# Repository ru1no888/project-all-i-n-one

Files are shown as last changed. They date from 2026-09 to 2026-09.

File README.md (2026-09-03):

# ระบบอุปกรณ์สวมใส่ติดตามสัญญาณชีพสุขภาพและเว็บแอปพลิเคชันบริหารจัดการคิวผู้ป่วยนอก
### (Hospital Queue Patient Portal & Smartwatch Health Monitoring)

---

## 📌 บทนำและภาพรวมโครงงาน (Overview)
โครงงานนี้เป็นการวิจัยและพัฒนานวัตกรรมระบบอุปกรณ์สวมใส่อัจฉริยะ (Smartwatch) ร่วมกับเว็บแอปพลิเคชันบริหารจัดการคิวผู้ป่วยนอกของโรงพยาบาล เพื่อยกระดับความปลอดภัยของผู้ป่วยในระหว่างรอรับการตรวจรักษา โดยระบบสามารถ:
1. **ติดตามสัญญาณชีพแบบเรียลไทม์ (Continuous Vital Signs Monitoring):** วัดอัตราการเต้นของหัวใจ (Heart Rate) และระดับความอิ่มตัวของออกซิเจนในเลือด ($SpO_2$) พร้อมคำนวณดัชนีช็อก (Shock Index: $SI = \frac{HR}{SBP}$) เพื่อประเมินภาวะวิกฤตของผู้ป่วย
2. **ตรวจจับอุบัติเหตุการหกล้ม (Multi-Stage Fall Detection):** ตรวจจับสภาวะการตกอิสระ (Free-fall), แรงกระแทก (Impact $SVM > 2.5g$) และสภาวะแน่นิ่งผิดปกติ (Inactivity) ด้วยเซนเซอร์ IMU 6 แกน
3. **จัดลำดับความเร่งด่วนของคิวอัตโนมัติ (Dynamic Queue Prioritization):** คัดกรองและปรับลำดับคิวผู้ป่วยตามหลักเกณฑ์ฉุกเฉิน ESI Version 4 ผ่านระบบ AI Triage เมื่อพบสัญญาณชีพวิกฤต
4. **แจ้งเตือนและส่งข้อมูลแบบทันที (Realtime Communication):** ส่งสัญญาณเตือนไปยังห้องพยาบาลและบุคลากรทางการแพทย์ผ่าน WebSockets ทันทีที่มีเหตุฉุกเฉิน

---

## 📁 โครงสร้างโฟลเดอร์ภายในโปรเจกต์ (Repository Structure)

```text
├── 01_เล่มรายงานโครงงาน_Thesis/
│   ├── เล่มรายงานโครงงาน_ฉบับสมบูรณ์_FINAL_v3_IEEE.docx    # เล่มรายงานโครงงานฉบับสมบูรณ์ (ฟอร์แมต IEEE มทร.อีสาน ขอนแก่น)
│   ├── เล่มรายงานโครงงาน_ฉบับสมบูรณ์_FINAL_v3_IEEE.pdf     # ไฟล์ PDF เล่มสมบูรณ์ (103 หน้า พร้อมตรวจ/พิมพ์)
│   ├── ECP-P01_แบบร่างโครงงานวิศวกรรมคอมพิวเตอร์_ฉบับปรับปรุงสมบูรณ์_v14.docx # แบบร่างข้อเสนอโครงงาน (Proposal v14)
│   ├── ECP-P01_แบบร่างโครงงานวิศวกรรมคอมพิวเตอร์_ฉบับปรับปรุงสมบูรณ์_v14.pdf  # ไฟล์ PDF แบบร่างโครงงาน (20 หน้าเต็ม)
│   └── ร่างเดิมและไฟล์สำรอง_Archive/                     # โฟลเดอร์สำรองไฟล์ดราฟต์เดิมทั้งหมดอย่างปลอดภัย
│
├── 02_ฮาร์ดแวร์และวงจร_Hardware/
│   ├── smartwatch_component_pinouts.html                 # ผังการต่อสาย Pinout และวงจรเซนเซอร์แบบ Interactive Web
│   ├── component_pinouts/                                # แผนภาพ Pinout รายชิ้นส่วน
│   ├── pcb_design/                                       # ไฟล์ออกแบบแผ่นวงจรพิมพ์ PCB (KiCad / EasyEDA)
│   └── pcb_design.zip                                    # ไฟล์บีบอัดสำหรับส่งโรงงานผลิต PCB (Gerber Files)
│
├── 03_ซอร์สโค้ดและเว็บแอป_SourceCode/
│   ├── repo_README.md                                    # เอกสารคู่มือการติดตั้งและการรัน Frontend Web App
│   ├── repo_ARCHITECTURE.md                              # สถาปัตยกรรมระบบ Frontend & Backend API Spec
│   ├── repo_package.json                                 # รายการ Dependencies (Next.js 14, React, Tailwind CSS)
│   ├── repo_patient-api.ts                               # API Client Module สำหรับเชื่อมต่อระบบโรงพยาบาล
│   ├── repo_types.ts                                     # TypeScript Interface สำหรับ Patient, Queue, Vital Signs
│   └── repo_mock_backend.py                              # สคริปต์จำลองเซิร์ฟเวอร์ Mock API สำหรับการทดสอบระบบ
│
├── 04_ไฟล์ข้อมูลและเครื่องมือเสริม_Assets_Tools/
│   ├── extracted_assets/                                 # รูปภาพและกราฟิกประกอบที่ใช้ในเอกสาร
│   ├── extracted_ch4_images/                             # ภาพผลการทดลองและการทดสอบระบบในบทที่ 4
│   ├── logo/                                             # ตราสัญลักษณ์มหาวิทยาลัยเทคโนโลยีราชมงคลอีสาน
│   └── build_full_thesis.py                              # สคริปต์สำหรับบิวด์และจัดรูปแบบรูปเล่มอัตโนมัติ
│
├── AGENTS.md                                             # ข้อกำหนดและแนวทางสำหรับ AI Assistant
├── GEMINI.md                                             # กฎระเบียบข้อบังคับและ Memory Protocol ประจำโปรเจกต์
├── PROJECT_MEMORY.md                                     # บันทึกความจำระยะยาว ประวัติการพัฒนา และข้อสรุปงาน
└── README.md                                             # เอกสารภาพรวมโปรเจกต์ (ไฟล์นี้)
```

---

## 🛠️ รายละเอียดสเปกฮาร์ดแวร์และเซนเซอร์ (Hardware Specifications)

| ส่วนประกอบ (Component) | รายละเอียด (Specification) | ฟังก์ชันการทำงาน |
|---|---|---|
| **MCU Controller** | Seeed Studio XIAO ESP32-C3 | หน่วยประมวลผลหลัก รองรับ Wi-Fi 2.4GHz และ BLE 5.0 |
| **Biometric Sensor** | MAX32664 Biometric Hub + MAX30102 PPG | ตรวจวัด Pulse Rate และ $SpO_2$ ด้วยความแม่นยำสูง |
| **Motion Sensor** | MPU-6050 (6-Axis Accel + Gyro) | ตรวจจับการเคลื่อนไหวและการหกล้ม 3 ขั้นตอน (SVM Analysis) |
| **Power Management** | TP4056 + แบตเตอรี่ LiPo 3.7V (500mAh) | วงจรชาร์จแบตเตอรี่ พร้อมวงจรแบ่งแรงดันวัดระดับแบตเตอรี่ |
| **Display** | จอแสดงผล OLED 0.96 นิ้ว (I2C) | แสดงผลอัตราเต้นหัวใจ, ออกซิเจนในเลือด และสถานะคิว |

---

## 💻 เทคโนโลยีฝั่งเว็บแอปพลิเคชัน (Software Stack)
- **Frontend Framework:** Next.js (App Router), React 18, TypeScript
- **Styling & UI:** Tailwind CSS, Lucide Icons, Headless UI
- **Database & Realtime:** Google Cloud Firestore, WebSockets
- **Deployment:** Vercel / Docker Container

---

## 👥 ผู้จัดทำโครงงาน (Contributors)
- **นายปรเมศว์ เดนนิส โฮค อาร์ริงตัน** (Mr. Porramet Dennis Hoke Arrington)
- **นายธนกร สุภาวรรณชัย** (Mr. Thanakorn Suphawanchai)

**สาขาวิชาวิศวกรรมคอมพิวเตอร์ คณะวิศวกรรมศาสตร์**  
**มหาวิทยาลัยเทคโนโลยีราชมงคลอีสาน วิทยาเขตขอนแก่น**  
**อาจารย์ที่ปรึกษาโครงงาน:** อาจารย์อรินธร เจษฎาเมธาขจร  
**ปีการศึกษา:** 2568 (Academic Year 2025)

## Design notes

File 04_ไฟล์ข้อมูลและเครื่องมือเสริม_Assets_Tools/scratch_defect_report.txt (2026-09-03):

=== 1. PLACEHOLDER & ERROR SCAN ===

=== 2. FIGURE NUMBERING SCAN ===
P138: รูปที่ 3.1 -> รูปที่ 3.1 แผนภาพ Use Case Diagram และสถาปัตยกรรมระบบรวม . . . . . . . . 48
P139: รูปที่ 3.2 -> รูปที่ 3.2 โมเดล 3D CAD ตัวเรือนนาฬิกา Smartwatch (SmartWatchV13 Comparison) . 5
P140: รูปที่ 3.3 -> รูปที่ 3.3 ผังการทำงานของเฟิร์มแวร์ฮาร์ดแวร์บน ESP32-C3 (Hardware Flowchart) . 5
P141: รูปที่ 3.4 -> รูปที่ 3.4 ผังการทำงานของระบบคลาวด์และเว็บแดชบอร์ด (Software Flowchart) . 73
P142: รูปที่ 4.1 -> รูปที่ 4.1 หน้าจอเข้าสู่ระบบผ่าน ThaID และ PIN . . . . . . . . . . . . . 79
P143: รูปที่ 4.2 -> รูปที่ 4.2 หน้าจอเข้าสู่ระบบด้วยรหัส PIN ส่วนบุคคล . . . . . . . . . . . 80
P144: รูปที่ 4.3 -> รูปที่ 4.3 หน้าจอลงทะเบียนผู้ป่วยใหม่ ส่วนข้อมูลส่วนบุคคล . . . . . . . . 81
P145: รูปที่ 4.4 -> รูปที่ 4.4 หน้าจอระบุอาการสำคัญ โรคประจำตัว และประวัติแพ้ยา . . . . . . . 82
P146: รูปที่ 4.5 -> รูปที่ 4.5 หน้าจอบันทึกยาประจำ ที่อยู่ ผู้ติดต่อฉุกเฉิน และการยินยอม PDPA . 83
P147: รูปที่ 4.6 -> รูปที่ 4.6 หน้าจอบัตรคิวรับบริการดิจิทัลบนสมาร์ตโฟนของผู้ป่วย . . . . . . 84
P148: รูปที่ 4.7 -> รูปที่ 4.7 หน้าจอแสดงผลคิวรอตรวจรวมทั้งแผนก (Live OPD Board) . . . . . . 85
P149: รูปที่ 4.8 -> รูปที่ 4.8 หน้าจอตรวจสอบคิวสดพร้อมป๊อปอัปบัตรคิวดิจิทัล . . . . . . . . . 86
P150: รูปที่ 4.9 -> รูปที่ 4.9 หน้าจอข้อมูลส่วนบุคคลและข้อมูลสุขภาพผู้ป่วย . . . . . . . . . 87
P151: รูปที่ 4.10 -> รูปที่ 4.10 หน้าจอรายการนัดหมายตรวจรักษา . . . . . . . . . . . . . . . . 87
P152: รูปที่ 4.11 -> รูปที่ 4.11 หน้าจอประวัติการรับบริการและการบันทึกค่าสัญญาณชีพ . . . . . . 88
P153: รูปที่ 4.12 -> รูปที่ 4.12 หน้าจอรายละเอียดข้อมูลผู้ป่วยและสรุปประวัติสุขภาพ . . . . . . 88
P154: รูปที่ 4.13 -> รูปที่ 4.13 หน้าต่างยืนยันการยกเลิกคิวรับบริการ (ขั้นตอนที่ 1) . . . . . 89
P155: รูปที่ 4.14 -> รูปที่ 4.14 หน้าต่างยืนยันการยกเลิกคิวรับบริการ (ขั้นตอนที่ 2) . . . . . 89
P156: รูปที่ 4.15 -> รูปที่ 4.15 หน้าจอแสดงสถานะเมื่อไม่มีคิวรับบริการในขณะนั้น . . . . . . . 90
P157: รูปที่ 4.16 -> รูปที่ 4.16 หน้าต่างแจ้งเตือนเมื่อผู้ป่วยมีคิวที่กำลังรอตรวจอยู่แล้ว . . 90
P158: รูปที่ 4.17 -> รูปที่ 4.17 หน้าต่างยืนยันการออกจากระบบ . . . . . . . . . . . . . . . . . 91
P159: รูปที่ 4.18 -> รูปที่ 4.18 หน้าจอการตั้งค่าระบบและความปลอดภัย . . . . . . . . . . . . . 91
P160: รูปที่ 4.19 -> รูปที่ 4.19 หน้าจอกรอกรหัส PIN 6 หลักสำหรับความปลอดภัย . . . . . . . . . 91
P161: รูปที่ 4.20 -> รูปที่ 4.20 หน้าจอยืนยันรหัส PIN 6 หลัก . . . . . . . . . . . . . . . . . 92
P162: รูปที่ 4.21 -> รูปที่ 4.21 หน้าจอแจ้งเตือนตั้งรหัส PIN สำเร็จ . . . . . . . . . . . . . 92
P163: รูปที่ 4.22 -> รูปที่ 4.22 หน้าจอปลดล็อกแอปพลิเคชันด้วย PIN . . . . . . . . . . . . . . 92
P164: รูปที่ 4.23 -> รูปที่ 4.23 หน้าจอแจ้งเตือนเมื่อกรอกรหัส PIN ไม่ถูกต้อง . . . . . . . . . 93
P165: รูปที่ 4.24 -> รูปที่ 4.24 หน้าจอตั้งค่าขนาดตัวอักษร (Accessibility) สำหรับผู้สูงอายุ . 93
P166: รูปที่ 4.25 -> รูปที่ 4.25 หน้าจอนโยบายความเป็นส่วนตัวและคุ้มครองข้อมูลสุขภาพ (PDPA Policy) . 9
P167: รูปที่ 4.26 -> รูปที่ 4.26 หน้าจอ Landing Page ยินดีต้อนรับผู้รับบริการ . . . . . . . . 94
P331: รูปที่ 3.1 -> รูปที่ 3.1 แผนภาพ Use Case Diagram และสถาปัตยกรรมระบบรวม
P339: รูปที่ 3.2 -> รูปที่ 3.2 โมเดล 3D CAD ตัวเรือนนาฬิกา Smartwatch (SmartWatchV13 Comparison)
P341: รูปที่ 3.3 -> การทำงานของเฟิร์มแวร์บนตัวอุปกรณ์สวมใส่ถูกควบคุมด้วยเครื่องสถานะจำกัด (Finite St
P343: รูปที่ 3.3 -> รูปที่ 3.3 ผังการทำงานของเฟิร์มแวร์ฮาร์ดแวร์บน ESP32-C3 (Hardware Flowchart)
P376: รูปที่ 3.4 -> รูปที่ 3.4 ผังการทำงานของระบบคลาวด์และเว็บแดชบอร์ด (Software Flowchart)
P391: รูปที่ 4.1 -> ระบบเว็บแอปพลิเคชันได้รับการพัฒนาขึ้นอย่างสมบูรณ์ รองรับการทำงานทั้งบนอุปกรณ์คอม
P393: รูปที่ 4.1 -> รูปที่ 4.1 หน้าจอเข้าสู่ระบบผ่าน ThaID และ PIN
P395: รูปที่ 4.2 -> รูปที่ 4.2 หน้าจอเข้าสู่ระบบด้วยรหัส PIN ส่วนบุคคล
P397: รูปที่ 4.3 -> รูปที่ 4.3 หน้าจอลงทะเบียนผู้ป่วยใหม่ ส่วนข้อมูลส่วนบุคคล
P399: รูปที่ 4.4 -> รูปที่ 4.4 หน้าจอระบุอาการสำคัญ โรคประจำตัว และประวัติแพ้ยา
P401: รูปที่ 4.5 -> รูปที่ 4.5 หน้าจอบันทึกยาประจำ ที่อยู่ ผู้ติดต่อฉุกเฉิน และการยินยอม PDPA
P403: รูปที่ 4.6 -> รูปที่ 4.6 หน้าจอบัตรคิวรับบริการดิจิทัลบนสมาร์ตโฟนของผู้ป่วย
P405: รูปที่ 4.7 -> รูปที่ 4.7 หน้าจอแสดงผลคิวรอตรวจรวมทั้งแผนก (Live OPD Board)
P407: รูปที่ 4.8 -> รูปที่ 4.8 หน้าจอตรวจสอบคิวสดพร้อมป๊อปอัปบัตรคิวดิจิทัล
P409: รูปที่ 4.9 -> รูปที่ 4.9 หน้าจอข้อมูลส่วนบุคคลและข้อมูลสุขภาพผู้ป่วย
P411: รูปที่ 4.10 -> รูปที่ 4.10 หน้าจอรายการนัดหมายตรวจรักษา
P413: รูปที่ 4.11 -> รูปที่ 4.11 หน้าจอประวัติการรับบริการและการบันทึกค่าสัญญาณชีพ
P415: รูปที่ 4.12 -> รูปที่ 4.12 หน้าจอรายละเอียดข้อมูลผู้ป่วยและสรุปประวัติสุขภาพ
P417: รูปที่ 4.13 -> รูปที่ 4.13 หน้าต่างยืนยันการยกเลิกคิวรับบริการ (ขั้นตอนที่ 1)
P419: รูปที่ 4.14 -> รูปที่ 4.14 หน้าต่างยืนยันการยกเลิกคิวรับบริการ (ขั้นตอนที่ 2)
P421: รูปที่ 4.15 -> รูปที่ 4.15 หน้าจอแสดงสถานะเมื่อไม่มีคิวรับบริการในขณะนั้น
P423: รูปที่ 4.16 -> รูปที่ 4.16 หน้าต่างแจ้งเตือนเมื่อผู้ป่วยมีคิวที่กำลังรอตรวจอยู่แล้ว
P425: รูปที่ 4.17 -> รูปที่ 4.17 หน้าต่างยืนยันการออกจากระบบ
P427: รูปที่ 4.18 -> รูปที่ 4.18 หน้าจอการตั้งค่าระบบและความปลอดภัย
P429: รูปที่ 4.19 -> รูปที่ 4.19 หน้าจอกรอกรหัส PIN 6 หลักสำหรับความปลอดภัย
P431: รูปที่ 4.20 -> รูปที่ 4.20 หน้าจอยืนยันรหัส PIN 6 หลัก
P433: รูปที่ 4.21 -> รูปที่ 4.21 หน้าจอแจ้งเตือนตั้งรหัส PIN สำเร็จ
P435: รูปที่ 4.22 -> รูปที่ 4.22 หน้าจอปลดล็อกแอปพลิเคชันด้วย PIN
P437: รูปที่ 4.23 -> รูปที่ 4.23 หน้าจอแจ้งเตือนเมื่อกรอกรหัส PIN ไม่ถูกต้อง
P439: รูปที่ 4.24 -> รูปที่ 4.24 หน้าจอตั้งค่าขนาดตัวอักษร (Accessibility) สำหรับผู้สูงอายุ
P441: รูปที่ 4.25 -> รูปที่ 4.25 หน้าจอนโยบายความเป็นส่วนตัวและคุ้มครองข้อมูลสุขภาพ (PDPA Policy)
P443: รูปที่ 4.26 -> รูปที่ 4.26 หน้าจอ Landing Page ยินดีต้อนรับผู้รับบริการ

=== 3. TABLE NUMBERING SCAN ===
P119: ตารางที่ 1.1 -> ตารางที่ 1.1 แผนการดำเนินงานและแผนภูมิแกนต์ตลอด 2 ภาคการศึกษา . . . . . . 8
P120: ตารางที่ 1.2 -> ตารางที่ 1.2 ประมาณการงบประมาณและค่าใช้จ่ายในการพัฒนาโครงงาน (BOM) . . . . 9
P121: ตารางที่ 2.1 -> ตารางที่ 2.1 เกณฑ์ค่ามาตรฐานสัญญาณชีพและระดับภาวะวิกฤตทางการแพทย์ (NEWS/MEWS) . 
P122: ตารางที่ 2.2 -> ตารางที่ 2.2 การเปรียบเทียบคุณสมบัติของเซนเซอร์ PPG และชิปประมวลผล . . . 22
P123: ตารางที่ 2.3 -> ตารางที่ 2.3 สรุปและเปรียบเทียบผลการศึกษางานวิจัยที่เกี่ยวข้องกับโครงงาน . 43
P124: ตารางที่ 3.1 -> ตารางที่ 3.1 การเชื่อมต่อพินระหว่าง ESP32-C3 กับโมดูลเซนเซอร์และอุปกรณ์ต่อพ่วง .
P125: ตารางที่ 3.2 -> ตารางที่ 3.2 แบบจำลองการแปลงค่าแรงดันเป็นร้อยละความจุแบตเตอรี่ LiPo (LUT) . 58
P126: ตารางที่ 3.3 -> ตารางที่ 3.3 ตารางโครงสร้างฐานข้อมูล 8 เอนทิตีหลักของระบบ . . . . . . . . 61
P127: ตารางที่ 3.4 -> ตารางที่ 3.4 ข้อกำหนดการสื่อสารข้อมูลระหว่างระบบเว็บและแม่ข่าย (API Contract Tab
P128: ตารางที่ 4.1 -> ตารางที่ 4.1 ผลการทดสอบอัตราการใช้พลังงานและระยะเวลาทำงานต่อเนื่องของอุปกรณ์ . 9
P129: ตารางที่ 4.2 -> ตารางที่ 4.2 ผลการเปรียบเทียบความแม่นยำของเซนเซอร์ Smartwatch กับเครื่องมือมาตรฐ
P130: ตารางที่ 4.3 -> ตารางที่ 4.3 ตาราง Confusion Matrix และประสิทธิภาพการจำแนกความรุนแรงของ AI Triag
P131: ตารางที่ 4.4 -> ตารางที่ 4.4 ผลการทดสอบประสิทธิภาพการตรวจจับการหกล้มและการจำแนกกิจกรรมประจำวัน .
P132: ตารางที่ 4.5 -> ตารางที่ 4.5 ผลการทดสอบกรณีจำลองการยืนยันและปรับแก้ผลการคัดแยกโดยพยาบาล . 105
P133: ตารางที่ 4.6 -> ตารางที่ 4.6 ตารางสรุปผลการประเมินการบรรลุวัตถุประสงค์ของโครงงาน (Objective Matr
P134: ตารางที่ 4.7 -> ตารางที่ 4.7 ผลการประเมินระดับความพึงพอใจของผู้ใช้งานต่อระบบ (N = 30) . 109
P249: ตารางที่ 1.1 -> การดำเนินงานโครงงานมีระยะเวลาตลอด 2 ภาคการศึกษา (ปีการศึกษา 2568) โดยมีแผนภูมิแก
P250: ตารางที่ 1.1 -> ตารางที่ 1.1 แผนการดำเนินงานและแผนภูมิแกนต์ตลอด 2 ภาคการศึกษา
P253: ตารางที่ 1.2 -> ค่าใช้จ่ายในการจัดหาอุปกรณ์ฮาร์ดแวร์ ชิ้นส่วนอิเล็กทรอนิกส์ และเครื่องมือในการพั
P254: ตารางที่ 1.2 -> ตารางที่ 1.2 ประมาณการงบประมาณและค่าใช้จ่ายในการพัฒนาโครงงาน (BOM)
P281: ตารางที่ 2.1 -> ตารางที่ 2.1 เกณฑ์ค่ามาตรฐานสัญญาณชีพและระดับภาวะวิกฤตทางการแพทย์ (NEWS/MEWS)
P292: ตารางที่ 2.2 -> ตารางที่ 2.2 การเปรียบเทียบคุณสมบัติของเซนเซอร์ PPG และชิปประมวลผล
P315: ตารางที่ 2.3 -> คณะผู้จัดทำได้ศึกษาและทบทวนวรรณกรรมที่เกี่ยวข้องกับการพัฒนาอุปกรณ์สวมใส่ติดตามสั
P316: ตารางที่ 2.3 -> ตารางที่ 2.3 สรุปและเปรียบเทียบผลการศึกษางานวิจัยที่เกี่ยวข้องกับโครงงาน
P333: ตารางที่ 3.1 -> การเชื่อมต่อระหว่างบอร์ด Seeed Studio XIAO ESP32-C3 กับโมดูลเซนเซอร์และอุปกรณ์ต่
P334: ตารางที่ 3.1 -> ตารางที่ 3.1 การเชื่อมต่อพินระหว่าง ESP32-C3 กับโมดูลเซนเซอร์และอุปกรณ์ต่อพ่วง
P348: ตารางที่ 3.2 -> 4) Battery Look-Up Table (LUT): แปลงค่าแรงดันแบตเตอรี่เป็นร้อยละความจุตามเส้นโค้
P349: ตารางที่ 3.2 -> ตารางที่ 3.2 แบบจำลองการแปลงค่าแรงดันเป็นร้อยละความจุแบตเตอรี่ LiPo (LUT)
P352: ตารางที่ 3.3 -> ฐานข้อมูลของระบบได้รับการออกแบบตามโครงสร้างเชิงสัมพันธ์ ประกอบด้วย 8 เอนทิตีหลัก
P353: ตารางที่ 3.3 -> ตารางที่ 3.3 ตารางโครงสร้างฐานข้อมูล 8 เอนทิตีหลักของระบบ
P363: ตารางที่ 3.4 -> การรับส่งข้อมูลระหว่างอุปกรณ์สวมใส่ เว็บแอปพลิเคชัน และระบบแม่ข่ายดำเนินการผ่าน 
P364: ตารางที่ 3.4 -> ตารางที่ 3.4 ข้อกำหนดการสื่อสารข้อมูลระหว่างระบบเว็บและแม่ข่าย (API Contract Tab
P445: ตารางที่ 4.1 -> อุปกรณ์ Smartwatch ต้นแบบได้รับการประกอบและทดสอบการทำงานของวงจรอิเล็กทรอนิกส์อย่
P446: ตารางที่ 4.1 -> ตารางที่ 4.1 ผลการทดสอบอัตราการใช้พลังงานและระยะเวลาทำงานต่อเนื่องของอุปกรณ์
P449: ตารางที่ 4.2 -> การทดสอบความถูกต้องและแม่นยำของเซนเซอร์ PPG (MAX32664 / MAX30102) บนอุปกรณ์ Smar
P450: ตารางที่ 4.2 -> ตารางที่ 4.2 ผลการเปรียบเทียบความแม่นยำของเซนเซอร์ Smartwatch กับเครื่องมือมาตรฐ
P453: ตารางที่ 4.3 -> ผลการทดสอบแบบจำลอง AI Triage ในการจำแนกระดับความรุนแรง 5 ระดับ (RED, PINK, YELLO
P454: ตารางที่ 4.3 -> ตารางที่ 4.3 ตาราง Confusion Matrix และประสิทธิภาพการจำแนกความรุนแรงของ AI Triag
P456: ตารางที่ 4.3 -> จากตารางที่ 4.3 พบว่าระบบมีความแม่นยำรวม (Overall Accuracy) เท่ากับร้อยละ 91.20 
P458: ตารางที่ 4.4 -> การทดสอบอัลกอริทึม Multi-Stage Fall Detection แบบ Finite State Machine ประกอบด้ว
P459: ตารางที่ 4.4 -> ตารางที่ 4.4 ผลการทดสอบประสิทธิภาพการตรวจจับการหกล้มและการจำแนกกิจกรรมประจำวัน
P466: ตารางที่ 4.5 -> การทดสอบการทำงานของ Nurse Dashboard ร่วมกับแนวคิด Human-in-the-loop แสดงตัวอย่าง
P467: ตารางที่ 4.5 -> ตารางที่ 4.5 ผลการทดสอบกรณีจำลองการยืนยันและปรับแก้ผลการคัดแยกโดยพยาบาล
P470: ตารางที่ 4.6 -> การประเมินผลการดำเนินงานเทียบกับวัตถุประสงค์ทั้ง 6 ข้อของโครงงาน แสดงสรุปในตาราง
P471: ตารางที่ 4.6 -> ตารางที่ 4.6 ตารางสรุปผลการประเมินการบรรลุวัตถุประสงค์ของโครงงาน (Objective Matr
P474: ตารางที่ 4.7 -> ผลการประเมินความพึงพอใจจากกลุ่มตัวอย่างผู้รับบริการและบุคลากรทางการแพทย์จำนวน 30
P475: ตารางที่ 4.7 -> ตารางที่ 4.7 ผลการประเมินระดับความพึงพอใจของผู้ใช้งานต่อระบบ (N = 30)

=== 4. EQUATION NUMBERING SCAN ===
P284: สมการ (2.1) -> สัญญาณชีพเป็นตัวบ่งชี้สรีรวิทยาพื้นฐานที่สะท้อนถึงการทำงานของระบบสำคัญในร่างกาย 
P288: สมการ (2.2) -> เทคนิคโฟโตพลีทิสโมกราฟี (Photoplethysmography: PPG) เป็นการตรวจวัดทางทัศนศาสตร์โ
P290: สมการ (2.3) -> จากนั้นจะนำค่า R ไปแปลงเป็นค่าความอิ่มตัวของออกซิเจนในเลือด (SpO2) ผ่านสมการเทีย
P295: สมการ (2.4) -> การตรวจจับการหกล้มด้วยเซนเซอร์วัดความเฉื่อย 6 แกน (MPU-6050) อาศัยการคำนวณค่าเวก
P336: สมการ (3.1) -> การตรวจวัดแรงดันแบตเตอรี่ใช้วงจรแบ่งแรงดัน (Voltage Divider) ความต้านทาน R1 = 10
P379: สมการ (3.2) -> 1. การทดสอบความแม่นยำเซนเซอร์สัญญาณชีพ: เปรียบเทียบค่า HR, SpO2, Skin Temp, และ 
P382: สมการ (3.4) -> 2. การทดสอบการตรวจจับการหกล้ม: จำลองการหกล้มจริง 4 รูปแบบ (ล้มไปข้างหน้า ข้างหลั

=== 5. CHAPTER HEADINGS SCAN ===
P60: บทที่ 1 บทนำ . . . . . . . . . . . . . . . . . . . . . . . . . . . . . . . 1
P71: บทที่ 2 ทฤษฎีและงานวิจัยที่เกี่ยวข้อง . . . . . . . . . . . . . . . . . . 13
P84: บทที่ 3 วิธีดำเนินงาน . . . . . . . . . . . . . . . . . . . . . . . . . . 45
P95: บทที่ 4 ผลการดำเนินงานและการทดสอบระบบ . . . . . . . . . . . . . . . . . . 78
P105: บทที่ 5 สรุปผล อภิปรายผล และข้อเสนอแนะ . . . . . . . . . . . . . . . . . 110
P110: บรรณานุกรม . . . . . . . . . . . . . . . . . . . . . . . . . . . . . . . 118
P111: ภาคผนวก . . . . . . . . . . . . . . . . . . . . . . . . . . . . . . . . 123
P112: ภาคผนวก ก: ผังวงจรและการต่อสายสัญญาณ (Schematic & BOM) . . . . . . . 124
P113: ภาคผนวก ข: ซอร์สโค้ดสำคัญของระบบ (Source Code Snippets & Contracts) . 128
P114: ภาคผนวก ค: คู่มือการใช้งานระบบ Smartwatch และ Web Dashboard . . . . . 134
P115: ภาคผนวก ง: แบบประเมินความพึงพอใจและตารางบันทึกผลการทดสอบดิบ . . . . . 140
P195: บทที่ 1
บทนำ
P272: บทที่ 2
ทฤษฎีและงานวิจัยที่เกี่ยวข้อง
P319: บทที่ 3
วิธีดำเนินงาน
P388: บทที่ 4
ผลการดำเนินงานและการทดสอบระบบ
P478: บทที่ 5
สรุปผล อภิปรายผล และข้อเสนอแนะ
P503: บรรณานุกรม
P525: ภาคผนวก ก
ผังวงจรและการต่อสายสัญญาณ (Schematic & BOM)
P532: ภาคผนวก ข
ซอร์สโค้ดสำคัญของระบบ (Source Code Snippets & Contracts)
P543: ภาคผนวก ค
คู่มือการใช้งานระบบ Smartwatch และ Web Dashboard
P560: ภาคผนวก ง
แบบประเมินความพึงพอใจและตารางบันทึกผลการทดสอบดิบ

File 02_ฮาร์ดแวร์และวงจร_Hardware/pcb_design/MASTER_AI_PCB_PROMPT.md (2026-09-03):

# 🤖 MASTER AI PCB PROMPT: SMARTWATCH CARRIER BOARD v1.0
> **คำแนะนำ:** คุณสามารถคัดลอกข้อความด้านล่างนี้ทั้งหมด นำไปวางในช่องแชทของ AI (ChatGPT, Claude, Gemini, Antigravity) เพื่อให้ AI สร้างหรือปรับปรุงไฟล์ KiCad, Gerber, PDF และโค้ดวงจรนี้ใหม่ได้ทันที 100% โดยไม่มีข้อผิดพลาด

```markdown
คุณคือวิศวกรผู้เชี่ยวชาญด้านการออกแบบวงจรพิมพ์ (Hardware & PCB Design Engineer) ระดับสูง
โปรดช่วยฉันออกแบบและสร้างไฟล์ PCB สำหรับโปรเจกต์ "SmartWatch Carrier Board v1.0" บน KiCad โดยยึดตามข้อกำหนดทางวิศวกรรมและพิกัดเรขาคณิตขั้นสูงดังต่อไปนี้อย่างเคร่งครัด:

---

### 1. ข้อมูลภาพรวมและข้อกำหนดเชิงกล (Mechanical Constraints)
1. รูปร่างบอร์ด: แผ่น PCB ทรงกลม ขนาดเส้นผ่านศูนย์กลาง Ø 44.0 mm (รัศมี R = 22.0 mm) จุดกึ่งกลางบอร์ดอยู่ที่พิกัด (X = 100.0 mm, Y = 100.0 mm) บนเลเยอร์ Edge.Cuts
2. เลเยอร์บอร์ด: PCB 2 เลเยอร์ (Top Layer: F.Cu และ Bottom Layer: B.Cu), เนื้อแผ่น FR-4 หนา 1.0 mm (เพื่อความบางสำหรับใส่นาฬิกา), ทองแดงหนา 1 oz (35 µm)
3. กฎความปลอดภัยของขอบบอร์ด (Strict Keep-In DRC Rule):
   - ขาอุปกรณ์ (Pads), รูเจาะ (Drills), ลายเส้นทองแดง (Tracks) และรูเวีย (Vias) ทั้งหมดจะต้องอยู่ภายในรัศมีปลอดภัย:
     $$\sqrt{(X - 100.0)^2 + (Y - 100.0)^2} \le 19.2\text{ mm}$$
   - รับประกันว่าทุกชิ้นส่วนจะอยู่ห่างจากขอบวงกลมจริงอย่างน้อย 2.8 mm ห้ามมีส่วนใดยื่นหลุดขอบเด็ดขาด (Zero Edge Protrusion)
4. พื้นที่เว้นว่างเสาอากาศ (Antenna Keep-Out Zone):
   - สี่เหลี่ยมผืนผ้าด้านบนกึ่งกลาง (X = 93.5 ถึง 106.5 mm, Y = 81.5 ถึง 85.5 mm)
   - ห้ามวางชิ้นส่วน ห้ามลากลายเส้น และห้ามเททองแดง (No Copper Fill) ทั้ง 2 ด้าน เพื่อให้เสาอากาศ 2.4GHz Wi-Fi/BLE ของ ESP32 ทำงานได้เต็มประสิทธิภาพ
5. สถาปัตยกรรมแยก 2 หน้า (Dual-Sided Component Placement):
   - หน้าบน (Top Layer: F.Cu): ติดตั้งเฉพาะขั้วต่อหน้าจอ GC9A01 Round TFT 7 ขา (1x7 Header) ที่แนวแกน Y = 106.5 mm
   - หน้าหลัง (Bottom Layer: B.Cu): ติดตั้งบอร์ด MCU (XIAO ESP32-C3), เซนเซอร์ MPU6050, ขั้วต่อเซนเซอร์ชีพจร Pulse Express, วงจรขับบัซเซอร์, วงจรแบ่งแรงดันวัดแบตเตอรี่ และแถบควบคุมพลังงาน (สวิตช์/ฟิวส์/ขั้วแบต)

---

### 2. รายการอุปกรณ์ พิกัดตำแหน่ง และฟุตพริ้นท์ (Component Footprint Mapping)
จัดวางอุปกรณ์ทุกตัวบน Bottom Layer (B.Cu) ยกเว้น DISP1 ดังนี้:
1. U1 (Seeed Studio XIAO ESP32-C3):
   - ซ็อคเก็ตตัวเมีย 1x7 สองแถว ระยะห่างแถว 15.4 mm วางกึ่งกลางที่ (X = 100.0 mm, Y = 95.0 mm)
   - แถวซ้าย (X = 92.3 mm, Y = 87.38 ถึง 102.62 mm): ขา 1=D0, 2=D1, 3=D2, 4=D3, 5=D4, 6=D5, 7=D6
   - แถวขวา (X = 107.7 mm, Y = 87.38 ถึง 102.62 mm): ขา 14=5V, 13=GND, 12=3V3, 11=D10, 10=D9, 9=D8, 8=D7
2. DISP1 (GC9A01 240x240 Round TFT 7-Pin):
   - อยู่หน้าบน (F.Cu) ที่ตำแหน่ง (X = 100.0 mm, Y = 106.5 mm)
   - ขา 1=3V3, 2=GND, 3=SCK, 4=MOSI, 5=DC, 6=GND/CS, 7=RST (ระยะ Pitch 2.54 mm)
3. U3 (MPU6050 6-Axis Fall Detection Sensor):
   - ขั้วต่อตัวเมีย 1x8 (2.54mm Pitch) วางแนวตั้งทางฝั่งซ้ายที่ (X = 86.0 mm, Y = 96.0 mm)
   - ขา 1=3V3, 2=GND, 3=SCL, 4=SDA, 5=NC, 6=NC, 7=GND, 8=NC (ห่างจาก MCU 6.3 mm)
4. U2_CONN (SparkFun Pulse Express MAX32664D/MAX30102):
   - ขั้วต่อ JST-SH 1.0mm 6-Pin SMD แนวตั้ง วางทางฝั่งขวาที่ (X = 114.0 mm, Y = 96.0 mm)
   - ขา 1=5V_SYS, 2=GND, 3=I2C_SDA, 4=I2C_SCL, 5=HUB_MFIO, 6=HUB_RESET (ห่างจาก MCU 6.3 mm)
5. วงจรขับบัซเซอร์ (Buzzer Driver Zone - มุมบนซ้าย):
   - BZ1 (Active Buzzer 3.3V 9x5.5mm): วางที่ (X = 90.0 mm, Y = 85.5 mm) รูเจาะ Lead Pitch 3.6 mm
   - Q1 (S8050 NPN Transistor): ฟุตพริ้นท์ SOT-23 SMD วางที่ (X = 94.0 mm, Y = 86.0 mm)
   - R3 (ตัวต้านทาน 1kΩ 0805 SMD): วางที่ (X = 94.0 mm, Y = 89.5 mm)
   - R4 (ตัวต้านทาน 100kΩ 0805 SMD): วางที่ (X = 90.0 mm, Y = 90.0 mm)
6. วงจรแบ่งแรงดันวัดระดับแบตเตอรี่ (Battery Sense Zone - มุมบนขวา):
   - R1 (ตัวต้านทาน 200kΩ ±1% 0805 SMD): วางที่ (X = 106.0 mm, Y = 86.5 mm)
   - R2 (ตัวต้านทาน 200kΩ ±1% 0805 SMD): วางที่ (X = 106.0 mm, Y = 89.5 mm)
   - C1 (ตัวเก็บประจุ 100nF 0805 SMD): วางที่ (X = 106.0 mm, Y = 92.5 mm)
7. แถบควบคุมพลังงานขอบล่าง (Power Management Strip - แนวนอน Y = 112.5 ถึง 113.0 mm):
   - F1 (ฟิวส์ตัดตอนอัตโนมัติ PTC 0.5A 1206 SMD): วางที่ (X = 89.5 mm, Y = 112.5 mm)
   - SW1 (สวิตช์เลื่อนเปิด-ปิด SPDT PCM12 SMD): วางที่ (X = 95.0 mm, Y = 112.5 mm)
   - J1 (ขั้วต่อแบตเตอรี่ LiPo 3.7V JST-PH 2.0mm 2-Pin): วางที่ (X = 101.0 mm, Y = 113.0 mm)
   - D1 (ไดโอดช็อตต์กี SS14 1A 40V SMA SMD): วางที่ (X = 107.5 mm, Y = 112.5 mm)

---

### 3. ตารางการเชื่อมต่อสัญญาณและโครงข่ายไฟฟ้า (Complete Netlist 20 Nets)
1. 5V_SYS       : D1(Pin 2) -> U1(Pin 14: 5V In) -> U2_CONN(Pin 1: VCC)
2. 3V3_SYS      : U1(Pin 12: 3V3 Out) -> DISP1(Pin 1) -> U3(Pin 1) -> BZ1(Pin 1)
3. GND_SYS      : U1(Pin 13) -> DISP1(Pin 2, Pin 6) -> U3(Pin 2, Pin 7) -> U2_CONN(Pin 2) -> Q1(Pin 2) -> R4(Pin 2) -> R2(Pin 2) -> C1(Pin 2) -> J1(Pin 2)
4. BAT_RAW+     : J1(Pin 1) -> F1(Pin 1)
5. BAT_OUT+     : F1(Pin 2) -> SW1(Pin 1)
6. SW_IN        : Alias ของ BAT_OUT+
7. BAT_SW+      : SW1(Pin 2) -> R1(Pin 1) และต่อเข้าโมดูล TP4056/Boost Step-Up
8. 5V_BOOST     : D1(Pin 1: Anode จากไฟ 5V บูสต์)
9. ADC_BAT      : U1(Pin 3: GPIO2/A2) -> R1(Pin 2) -> R2(Pin 1) -> C1(Pin 1)
10. HUB_MFIO    : U1(Pin 1: GPIO0/D0) -> U2_CONN(Pin 5)
11. HUB_RESET   : U1(Pin 2: GPIO1/D1) -> U2_CONN(Pin 6)
12. I2C_SDA     : U1(Pin 5: GPIO4/D4) -> U3(Pin 4) -> U2_CONN(Pin 3)
13. I2C_SCL     : U1(Pin 6: GPIO5/D5) -> U3(Pin 3) -> U2_CONN(Pin 4)
14. TFT_DC      : U1(Pin 7: GPIO6/D6) -> DISP1(Pin 5)
15. TFT_RST     : U1(Pin 8: GPIO7/D7) -> DISP1(Pin 7)
16. TFT_SCK     : U1(Pin 9: GPIO8/D8) -> DISP1(Pin 3)
17. TFT_MOSI    : U1(Pin 11: GPIO10/D10) -> DISP1(Pin 4)
18. BUZZER_CTL  : U1(Pin 4: GPIO3/D3) -> R3(Pin 1)
19. Q1_BASE     : R3(Pin 2) -> R4(Pin 1) -> Q1(Pin 1: Base)
20. BUZZER_NEG  : Q1(Pin 3: Collector) -> BZ1(Pin 2: ขาลบ)

---

### 4. กฎการเดินลายเส้นแบบแยกชั้นสมบูรณ์ (Topological Zero-Overlap Routing)
- กฎเหล็ก: ห้ามมีลายเส้นต่างสัญญาณวิ่งตัดกันบนเลเยอร์เดียวกันเด็ดขาด (Zero Overlap on Same Plane)
- การแบ่งหน้าที่ของเลเยอร์:
  * Top Layer (F.Cu - สีแดง): เดินเฉพาะเส้นสัญญาณจอแนวตั้ง TFT_MOSI (X = 100.0 mm), TFT_RST (X = 107.62 mm) และบัส I2C ข้ามไปฝั่งขวา
  * Bottom Layer (B.Cu - สีน้ำเงิน): เดินเส้น TFT_DC (Y = 104.5 mm), TFT_SCK (Y = 100.08 mm), 3V3_SYS (Y = 92.46 mm), 5V_SYS, ADC_BAT, สัญญาณควบคุม MFIO/RESET, วงจรบัซเซอร์ และระบบไฟล่าง
  * สัญญาณที่จำเป็นต้องตัดข้ามกันในเชิง 2D ให้ข้ามผ่านคนละเลเยอร์โดยมีเนื้อฉนวน FR-4 หนา 1.0 mm คั่นกลาง
- ขนาดความกว้างลายเส้น (Track Widths):
  * สายไฟกำลัง 5V และ แบตเตอรี่ (5V_SYS, BAT_RAW+, SW_IN, BAT_SW+): กว้าง 0.75 mm (29.5 mil)
  * สายไฟเลี้ยงระบบตรรกะ (3V3_SYS, GND): กว้าง 0.45 - 0.55 mm (17.7 - 21.6 mil)
  * สายสัญญาณข้อมูลความเร็วสูง (SPI, I2C, ADC, Controls): กว้าง 0.35 mm (13.8 mil)
  * ระยะ Clearance ระหว่างทองแดง: ไม่น้อยกว่า 0.35 mm
- ขนาดรูเจาะเวีย (Vias): ขนาดเส้นผ่านศูนย์กลาง 0.80 mm, ขนาดรูเจาะ Drill 0.40 mm

---

### 5. รูปแบบไฟล์ผลลัพธ์ที่ต้องการ (Required Outputs)
1. ไฟล์ KiCad PCB (`.kicad_pcb`): พร้อมฟุตพริ้นท์และลายเส้นเชื่อมต่อครบ 100% ผ่านการตรวจสอบ DRC (0 Errors)
2. ชุดไฟล์ Gerber & Drill ZIP: มาตรฐาน RS-274X ครบทุกเลเยอร์ทองแดง หน้ากาก (Mask), ซิลค์สกรีน (Silk) และรูเจาะ Excellon (`.drl`)
3. ไฟล์ PDF ขนาด 1:1 แบบ 3 หน้าสำหรับงานสร้างจริง:
   - หน้า 1: Bottom Layer (B.Cu) พลิกกระจก (Mirrored) ขาว-ดำ คมชัด สำหรับรีดเตารีดด้านหลัง
   - หน้า 2: Top Layer (F.Cu) หน้าตรงปกติ (Normal) ขาว-ดำ คมชัด สำหรับรีดเตารีดด้านหน้า
   - หน้า 3: แผนผังบอกตำแหน่งบัดกรีอุปกรณ์ (Assembly Map) พร้อมแถบวัดขนาดจริง 50 mm Calibration Bar
```

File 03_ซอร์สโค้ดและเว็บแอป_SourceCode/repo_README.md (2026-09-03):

# Hospital Queue Patient Portal

Patient-facing OPD queue portal built with Next.js App Router and TypeScript. It keeps the existing hospital backend contract unchanged.

## Requirements

- Node.js 20.9 or newer

## Run locally

```powershell
npm install
npm run dev
```

Open `http://localhost:3000`.

## Run the static build

The backend currently allows the patient portal origin at `http://127.0.0.1:5500`. Build and serve the exported site with:

```powershell
$env:PATIENT_API_BASE_URL="https://hospital.bfirstkok.me"
npm run build

cd dist
python -m http.server 5500 --bind 127.0.0.1
```

Open `http://127.0.0.1:5500`. Stop the server with `Ctrl+C`.

## Project structure

```text
src/
├─ app/                 Next.js entrypoint and global styles
├─ features/            Patient-facing flows, grouped by feature
│  ├─ account/
│  ├─ auth/
│  ├─ queue/
│  └─ registration/
└─ shared/              Code reused by multiple features
   ├─ api/              Backend contract, types, and fetch client
   ├─ auth/             Browser token storage
   ├─ config/           Runtime environment configuration
   └─ ui/               Shared layout components
```

Tests live next to the source file they cover. Import application code through the `@/` alias. See [docs/ARCHITECTURE.md](docs/ARCHITECTURE.md) before adding a feature.

## Runtime configuration

The client reads `window.PATIENT_APP_ENV` from `public/runtime-config.js` before the interactive UI starts.

For a production build, set the values below. The build writes `public/runtime-config.js`; do not commit a deployment-specific URL.

```powershell
$env:PATIENT_API_BASE_URL="https://hospital.bfirstkok.me"
$env:PATIENT_STATUS_REFRESH_MS="10000"
npm run build
```

`PATIENT_API_BASE_URL` must use HTTPS except for `localhost` or `127.0.0.1`. Copy [.env.example](.env.example) as a reference for local deployment settings.

## Verification

```powershell
npm run lint
npm run typecheck
npm run test
npm run build
```

## Backend contract retained

- `POST /api/patient/register/`
- `POST /api/patient/login/`
- `GET /api/patient/me/`
- `GET /api/patient/queue/`
- Browser storage key: `hospital_patient_access_token`
- Queue refresh: `STATUS_REFRESH_MS`, default `10000` ms

No Next.js API route is used. The hospital backend and dashboard are outside this repository and are not modified.

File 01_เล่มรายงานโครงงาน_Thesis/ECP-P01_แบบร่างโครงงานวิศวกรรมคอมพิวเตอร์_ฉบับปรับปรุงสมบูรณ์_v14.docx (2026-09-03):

แบบร่างโครงงานวิศวกรรมคอมพิวเตอร์ (ECP-P01)

สาขาวิชาวิศวกรรมคอมพิวเตอร์ คณะวิศวกรรมศาสตร์ มหาวิทยาลัยเทคโนโลยีราชมงคลอีสาน วิทยาเขตขอนแก่น

ภาคการศึกษาที่ 2 ปีการศึกษา 2568 (วันที่ 17 มกราคม พ.ศ. 2569)

รายชื่อผู้จัดทำโครงงานและอาจารย์ที่ปรึกษา
ลำดับ | ชื่อ - นามสกุล | รหัสนักศึกษา | เบอร์โทรศัพท์
1) | นายปรเมศว์ เดนนิส โฮค อาร์ริงตัน | 66332110168-3 | 091-129-3125
2) | นายธนกร สุภาวรรณชัย | 66332110082-0 | 080-068-6095

1. ชื่อหัวข้อโครงงาน (Project Title)
ภาษาไทย: | อุปกรณ์สวมใส่เพื่อการติดตามสุขภาพและเว็บแอปเช็คคิวผู้ป่วยนอก
ภาษาอังกฤษ: | Wearable Health Monitoring Device and Outpatient Queue Check Web Application

2. รูปแบบรายงาน (Report Format)
[ X ] ปริญญานิพนธ์ (Thesis) | [ ] รายงานเชิงเทคนิค (Technical Report)

3. หลักการและเหตุผล (Background and Rationale)

ในระบบการบริหารจัดการสาธารณสุขในปัจจุบัน แผนกผู้ป่วยนอก (Outpatient Department: OPD) มีบทบาทสำคัญอย่างยิ่งในการคัดกรองและจำแนกผู้ป่วยตามความรุนแรงของอาการ อย่างไรก็ตาม ปัญหาสำคัญที่พบอย่างต่อเนื่องและส่งผลต่อความปลอดภัยของผู้ป่วยคือ "ช่องว่างของการรอคอย" (Waiting Gap) ซึ่งหมายถึงช่วงเวลาที่ผู้ป่วยผ่านจุดคัดกรองเบื้องต้นแล้ว แต่ยังคงต้องนั่งรอพบแพทย์ในพื้นที่พักคอยเป็นระยะเวลานาน ในสภาวะที่ผู้ป่วยมีความหนาแน่นสูง บุคลากรทางการแพทย์ไม่สามารถตรวจติดตามการเปลี่ยนแปลงของสัญญาณชีพ (Vital Signs) ของผู้ป่วยทุกคนได้อย่างต่อเนื่อง ส่งผลให้สภาวะวิกฤตที่อาจเกิดขึ้นอย่างฉับพลันขณะรอตรวจ (Occult Deterioration) ไม่ได้รับการตรวจพบอย่างทันท่วงที นำไปสู่การเกิดภาวะแทรกซ้อนที่รุนแรงหรือการเสียชีวิตที่สามารถป้องกันได้

ความเสี่ยงดังกล่าวเกิดขึ้นอย่างมีนัยสำคัญในผู้ป่วยกลุ่มอาการก้ำกึ่ง เช่น ปวดศีรษะรุนแรง แน่นหน้าอก ปวดท้องฉับพลัน หรือเวียนศีรษะ ซึ่งในทางการแพทย์สามารถประเมินความเสี่ยงล่วงหน้าได้จากค่าดัชนีช็อก (Shock Index: SI) คำนวณจากอัตราส่วนของอัตราการเต้นของหัวใจต่อความดันโลหิตซิสโตลิก (SI = HR / SBP) โดยการศึกษาของ Rady et al. (1994) [1] พบว่าผู้ป่วยที่มีค่า SI > 0.9 มีความสัมพันธ์อย่างมีนัยสำคัญกับภาวะวิกฤตซ่อนเร้น (Occult Shock) และมีความจำเป็นต้องได้รับการรักษาอย่างเร่งด่วน แม้ว่าการวัดสัญญาณชีพภายนอกในครั้งแรกจะดูปกติก็ตาม นอกจากนี้ ในผู้ป่วยโรคหลอดเลือดสมองขาดเลือดเฉียบพลัน (Acute Ischemic Stroke) มีช่วงเวลาการรักษาฉุกเฉินที่จำกัด ข้อมูลเชิงปริมาณทางการแพทย์ของ Saver (2006) [2] ระบุว่าในทุกๆ 1 นาทีที่การรักษาล่าช้า เซลล์ประสาทสมองจะถูกทำลายถึง 1.9 ล้านเซลล์ และสมองจะแก่ตัวลงเทียบเท่ากับ 3.6 ปี เช่นเดียวกับภาวะหัวใจหยุดเต้นนอกโรงพยาบาล (Cardiac Arrest) ซึ่ง Larsen et al. (1993) [3] และสมาคมโรคหัวใจแห่งสหรัฐอเมริกา (AHA) ระบุว่า โอกาสการรอดชีวิตจะลดลงร้อยละ 7–10 ในทุกๆ 1 นาทีที่ผ่านไปโดยไม่ได้รับการกู้ชีพ สถิติจากองค์การอนามัยโลก (WHO, 2019) [4] ยังยืนยันว่ากลุ่มโรคหัวใจและหลอดเลือดเป็นสาเหตุการเสียชีวิตอันดับ 1 ของโลกถึง 17.9 ล้านคนต่อปี การวัดสัญญาณชีพเพียงครั้งเดียว ณ จุดคัดกรองจึงไม่เพียงพอในการรับประกันความปลอดภัยของผู้ป่วยในระหว่างการรอคอย

นอกเหนือจากความเสี่ยงทางสรีรวิทยาแล้ว ระบบการจัดการคิวผู้ป่วยในโรงพยาบาลส่วนใหญ่ยังคงเป็นระบบคิวแบบคงที่ (Static Queue) ที่ไม่สามารถปรับเปลี่ยนลำดับการตรวจตามระดับความรุนแรงของร่างกายที่ทรุดลงขณะรอคอยได้ คณะผู้จัดทำจึงได้นำศาสตร์ทางวิศวกรรมคอมพิวเตอร์และอินเทอร์เน็ตของสรรพสิ่ง (Internet of Things: IoT) มาประยุกต์ใช้เพื่อพัฒนาระบบเฝ้าระวังผู้ป่วยนอกแบบบูรณาการ โดยพัฒนาอุปกรณ์สวมใส่ติดตามสุขภาพต้นแบบ (Smartwatch Prototype) ที่ใช้เซนเซอร์ชีวการแพทย์ MAX32664 ร่วมกับ MAX30102 ในการตรวจวัดอัตราการเต้นของหัวใจ ระดับความอิ่มตัวออกซิเจนในเลือด (SpO2) และแนวโน้มความดันโลหิต พร้อมเซนเซอร์ MPU-6050 สำหรับตรวจจับการหกล้มหลายขั้นตอน (Multi-stage Fall Detection) ประมวลผลร่วมกับไมโครคอนโทรลเลอร์ XIAO ESP32-C3 และส่งข้อมูลสัญญาณชีพขึ้นสู่ระบบคลาวด์แบบไร้สาย ควบคู่กับการพัฒนาเว็บแอปพลิเคชันพอร์ทัลผู้ป่วยนอก (Next.js) ที่มีระบบสนับสนุนการคัดแยกความรุนแรงอัตโนมัติ 5 ระดับ (AI-assisted 5-Level Triage) ตามเกณฑ์ Emergency Severity Index (ESI) และ NEWS/MEWS มีการปรับลำดับคิวแบบพลวัต (Dynamic Queue Prioritization) เมื่อตรวจพบสัญญาณวิกฤต ซึ่งสอดคล้องกับงานวิจัยของ Kim et al. (2022) [5] ที่ชี้ว่าระบบติดตามสัญญาณชีพไร้สายช่วยลดภาระงานของบุคลากรทางการแพทย์ เพิ่มความปลอดภัยในการดูแลผู้ป่วย และยกระดับระบบบริการทางการแพทย์สู่มาตรฐาน Smart Healthcare ได้อย่างยั่งยืน

4. วัตถุประสงค์ของโครงงาน (Objectives)
4.1) | เพื่อออกแบบและพัฒนาอุปกรณ์สวมใส่ต้นแบบ (Smartwatch Prototype) ด้วยไมโครคอนโทรลเลอร์ XIAO ESP32-C3 ร่วมกับเซนเซอร์ MAX32664/MAX30102 และ MPU-6050 สำหรับตรวจวัดสัญญาณชีพ (อัตราการเต้นหัวใจ, SpO2, อุณหภูมิผิวหนัง, แนวโน้มความดันโลหิต) และตรวจจับการหกล้มหลายขั้นตอน (Multi-stage Fall Detection) โดยมีค่าความคลาดเคลื่อนเฉลี่ยสัมบูรณ์ (MAE) ของสัญญาณชีพไม่เกิน ±5% เมื่อเทียบกับอุปกรณ์มาตรฐาน
4.2) | เพื่อพัฒนาเว็บแอปพลิเคชันจัดการคิวผู้ป่วยนอก (Patient Portal Web Application) ด้วย Next.js และ Tailwind CSS พร้อมบัตรคิวดิจิทัลผ่าน Canvas API รองรับการแสดงผลสัญญาณชีพแบบเรียลไทม์ และระบบแจ้งเตือนสถานะคิวการรับบริการผ่านเครือข่ายอินเทอร์เน็ต
4.3) | เพื่อพัฒนาระบบสนับสนุนการตัดสินใจคัดแยกความรุนแรงผู้ป่วย (AI-assisted 5-Level Triage Decision Support System) ตามมาตรฐานสากล Emergency Severity Index (ESI Version 4) และกระทรวงสาธารณสุข ร่วมกับกฎทางคลินิก (Clinical Rule-based Overrides) ภายใต้แนวคิด Human-in-the-loop ให้พยาบาลเป็นผู้ยืนยันผล
4.4) | เพื่อพัฒนาระบบความมั่นคงปลอดภัยในการเข้าถึงข้อมูลสุขภาพ (ThaID Authentication, 6-digit PIN, PDPA Consent) และกลไกสำรองข้อมูลแบบออฟไลน์ (Offline Ring Buffer) บนอุปกรณ์สวมใส่กรณีสัญญาณ Wi-Fi ขัดข้อง
4.5) | เพื่อทดสอบและประเมินประสิทธิภาพของระบบทั้งด้านความแม่นยำของอุปกรณ์สวมใส่ ความไวและความจำเพาะของการตรวจจับการหกล้ม ความหน่วงเวลาของระบบ (Network Latency < 5 วินาที) และความพึงพอใจของบุคลากรทางการแพทย์และผู้ใช้งาน

5. ขอบเขตและข้อจำกัดของโครงงาน (Scope and Limitations)

5.1 ขอบเขตของระบบฮาร์ดแวร์และอุปกรณ์สวมใส่
5.1.1) | รองรับการใช้งานในลักษณะ 1 อุปกรณ์ต่อผู้ป่วย 1 คน ในระหว่างรอรับบริการที่แผนกผู้ป่วยนอก (OPD)
5.1.2) | ใช้ไมโครคอนโทรลเลอร์ Seeed Studio XIAO ESP32-C3 (สถาปัตยกรรม RISC-V 32-bit, 160 MHz) พร้อม Wi-Fi 2.4 GHz และ BLE 5.0
5.1.3) | ใช้เซนเซอร์ชีวการแพทย์ MAX32664 Biometric Sensor Hub ร่วมกับ MAX30102 ตรวจวัด HR, SpO2, Skin Temp และแนวโน้มความดันโลหิต
5.1.4) | ใช้เซนเซอร์วัดความเฉื่อย 6 แกน MPU-6050 ตรวจจับการหกล้มหลายขั้นตอน (Multi-stage Fall Detection: Free-fall, Impact SVM > 2.5g, Inactivity)
5.1.5) | แสดงผลสัญญาณชีพและสถานะระบบแบบเรียลไทม์ผ่านหน้าจอสีทรงกลม Round LCD ขนาด 1.28 นิ้ว (GC9A01 ความละเอียด 240x240 พิกเซล)
5.1.6) | ใช้แบตเตอรี่ Li-Po 3.7V 120 mAh พร้อมโมดูลชาร์จ TP4056 และวงจรแบ่งแรงดัน (Voltage Divider 1:1) ตรวจสอบแรงดันผ่าน Piecewise Linear LUT
5.1.7) | โครงสร้างตัวเรือนออกแบบด้วย Fusion 360 ขึ้นรูปด้วย 3D Printing (FDM) และแผงวงจรพิมพ์สองหน้า (Custom 2-Layer PCB)

5.2 ขอบเขตของระบบซอฟต์แวร์ เครือข่าย และฐานข้อมูลคลาวด์
5.2.1) | พัฒนาเว็บแอปพลิเคชันส่วนหน้า (Patient Portal Frontend) ด้วย Next.js (App Router), React, TypeScript และ Tailwind CSS (Responsive Design)
5.2.2) | ใช้ Cloud Firestore / Realtime Database เป็นฐานข้อมูลกลางในการจัดเก็บและซิงโครไนซ์ข้อมูลสุขภาพ สถานะคิว และประวัติการรับบริการแบบเรียลไทม์
5.2.3) | เชื่อมต่อสื่อสารระหว่างอุปกรณ์สวมใส่กับระบบคลาวด์ผ่านโพรโทคอล HTTP/RESTful API และ WebSockets เพื่อการแจ้งเตือนแบบทันทีทันใด
5.2.4) | ระบบบัตรคิวดิจิทัล (Digital Queue Card) สร้างบัตรคิวอิเล็กทรอนิกส์แบบไดนามิกผ่าน HTML5 Canvas API พร้อมรหัสคิวและเวลาโดยประมาณ
5.2.5) | ระบบยืนยันตัวตนและความปลอดภัย รองรับการเข้าสู่ระบบด้วย ThaID, รหัส PIN 6 หลัก, และบันทึกความยินยอมตาม พ.ร.บ. คุ้มครองข้อมูลส่วนบุคคล (PDPA)

5.3 ขอบเขตด้านระบบคัดแยกความรุนแรง (AI-assisted Triage & Dynamic Queue)
5.3.1) | จำแนกระดับความรุนแรงของผู้ป่วยออกเป็น 5 ระดับ ตามมาตรฐาน Emergency Severity Index (ESI Version 4): ระดับ 1 แดง, 2 ชมพู, 3 เหลือง, 4 เขียว, 5 ขาว
5.3.2) | วิเคราะห์อาการสำคัญ (Chief Complaint) ร่วมกับค่าสัญญาณชีพแบบผสมผสาน (Hybrid Rules Engine) โดยมี Clinical Overrides เช่น SpO2 < 90% หรือ SI > 0.9
5.3.3) | มีกลไกอธิบายเหตุผลประกอบการคัดแยก (Explainable AI Reasons) ภายใต้หลักการ Human-in-the-loop ให้พยาบาลเป็นผู้ยืนยันผลขั้นสุดท้าย
5.3.4) | ระบบจัดลำดับคิวแบบพลวัต (Dynamic Queue Prioritization) ปรับเลื่อนลำดับคิวของผู้ป่วยขึ้นอัตโนมัติเมื่อตรวจพบสัญญาณวิกฤตขณะรอตรวจ

5.4 ขอบเขตวิธีการทดสอบและเกณฑ์การประเมินผล
5.4.1) | การทดสอบความแม่นยำของเซนเซอร์: เทียบค่า HR และ SpO2 กับเครื่องมือแพทย์มาตรฐาน กำหนดเกณฑ์ MAE < ±5% และร้อยละความคลาดเคลื่อน (PE) < 5%
5.4.2) | การทดสอบการตรวจจับการหกล้ม: จำลองการหกล้มและกิจกรรมประจำวัน (ADL) กำหนดเกณฑ์ความไว (Sensitivity) > 90% และความจำเพาะ (Specificity) > 95%
5.4.3) | การทดสอบความหน่วงเวลาของระบบ (Latency): วัดเวลาตั้งแต่เซนเซอร์อ่านค่าจนแสดงผลบนหน้าจอเว็บ Dashboard เฉลี่ยไม่เกิน 3–5 วินาที
5.4.4) | การทดสอบความถูกต้องของระบบคัดแยก ESI: เทียบกับผลการวินิจฉัยของผู้เชี่ยวชาญทางการแพทย์ กำหนดเกณฑ์ความแม่นยำ (Accuracy) > 85%

5.5 ข้อจำกัดของโครงงาน (Limitations)
5.5.1) | อุปกรณ์ที่พัฒนาขึ้นเป็นต้นแบบเพื่อการศึกษาและการวิจัยเชิงวิศวกรรม ไม่ใช่อุปกรณ์ทางการแพทย์ที่ผ่านการรับรองเชิงพาณิชย์ ใช้เพื่อเฝ้าระวังแนวโน้มเท่านั้น
5.5.2) | สัญญาณ PPG ไวต่อสัญญาณรบกวนจากการเคลื่อนไหว (Motion Artifacts) การวัดที่แม่นยำผู้ป่วยต้องอยู่นิ่งขณะทำการตรวจวัด
5.5.3) | อุปกรณ์ต้องทำงานภายใต้เขตสัญญาณ Wi-Fi 2.4 GHz โดยมี Offline Ring Buffer เก็บข้อมูลสำรองได้ 200 รายการกรณีสัญญาณหลุด
5.5.4) | อุปกรณ์ต้นแบบใช้แบตเตอรี่ Li-Po ขนาดกะทัดรัด ระยะเวลาทำงานต่อเนื่องอยู่ที่ประมาณ 3–5 ชั่วโมงต่อการชาร์จหนึ่งครั้ง

6. ประโยชน์ที่คาดว่าจะได้รับ (Expected Benefits)
6.1) | ด้านผู้ป่วยและญาติ: ได้รับความปลอดภัยในระหว่างรอคอยการรักษา ลดความวิตกกังวลจากการรอคิวด้วยระบบบัตรคิวดิจิทัลที่สามารถตรวจสอบสถานะคิว เวลาโดยประมาณ และข้อมูลสุขภาพของตนเองได้แบบเรียลไทม์ผ่านสมาร์ตโฟน
6.2) | ด้านบุคลากรทางการแพทย์: ลดภาระงานซ้ำซ้อนของพยาบาลในการเดินวัดสัญญาณชีพซ้ำในพื้นที่พักคอย มีระบบแจ้งเตือนภัยล่วงหน้า (Early Warning Notification) เมื่อผู้ป่วยมีแนวโน้มเข้าสู่ภาวะวิกฤต ช่วยให้เข้าช่วยเหลือได้ทันท่วงที
6.3) | ด้านการบริหารจัดการโรงพยาบาล: ช่วยลดความแออัดในพื้นที่พักคอยแผนกผู้ป่วยนอก (OPD) ยกระดับการจัดลำดับคิวจากระบบคงที่เป็นระบบคิวแบบพลวัตตามระดับความรุนแรงจริง (Dynamic Queue Prioritization) สอดรับกับนโยบายโรงพยาบาลอัจฉริยะ (Smart Hospital)
6.4) | ด้านความถูกต้องของเวชระเบียน: ระบบบันทึกข้อมูลสัญญาณชีพอัตโนมัติลงฐานข้อมูลคลาวด์ ช่วยลดความผิดพลาดที่เกิดจากการจดบันทึกด้วยมือ (Human Error) และสามารถเรียกดูข้อมูลแนวโน้มสัญญาณชีพย้อนหลังเพื่อประกอบการวินิจฉัยของแพทย์ได้
6.5) | ด้านวิชาการและเทคโนโลยี: ได้องค์ความรู้และต้นแบบระบบบูรณาการทางวิศวกรรมคอมพิวเตอร์ที่เชื่อมโยงฮาร์ดแวร์ฝังตัว การประมวลผลสัญญาณชีวการแพทย์ อินเทอร์เน็ตของสรรพสิ่ง (IoT) และปัญญาประดิษฐ์คัดแยกความรุนแรงทางการแพทย์อย่างเป็นรูปธรรม

7. เทคโนโลยีและอุปกรณ์ที่ใช้ (Tools & Technology Stack)
ลำดับ | หมวดหมู่เทคโนโลยี | รายการอุปกรณ์ / ซอฟต์แวร์ / เครื่องมือที่ใช้
1 | 7.1 ส่วนระบบฮาร์ดแวร์และอุปกรณ์สวมใส่ | 1. Seeed Studio XIAO ESP32-C3 (RISC-V 32-bit, 160 MHz, Wi-Fi 2.4GHz / BLE 5.0) 2. MAX32664 Biometric Sensor Hub ร่วมกับ MAX30102 (HR, SpO2, Skin Temp, BP Trend) 3. MPU-6050 6-Axis IMU Sensor (3-Axis Accelerometer + 3-Axis Gyroscope) 4. 1.28-inch Round LCD Display (Controller GC9A01, 240x240 pixels, SPI Interface) 5. แบตเตอรี่ลิเธียมโพลิเมอร์ (Li-Po 3.7V 120mAh รหัส 401230) พร้อมโมดูลชาร์จ TP4056 6. แผ่นวงจรพิมพ์สั่งผลิตพิเศษ (Custom 2-Layer PCB) และกล่องตัวเรือน 3D Printed (PLA)
2 | 7.2 ส่วนระบบเฟิร์มแวร์และการประมวลผล ณ แหล่งกำเนิด | 1. Arduino IDE และ ESP-IDF Framework (ภาษา Embedded C/C++) 2. สถาปัตยกรรม Finite State Machine (FSM) ควบคุมการทำงานของฮาร์ดแวร์ 3. อัลกอริทึม Signal Quality Index (SQI) และ Skin-Contact Threshold กรองสัญญาณรบกวน 4. อัลกอริทึม Multi-Stage Fall Detection วิเคราะห์ความเร่งรวม Signal Vector Magnitude (SVM) 5. ระบบสำรองข้อมูลออฟไลน์ Offline Ring Buffer (200 ตัวอย่าง) และ Auto-reconnect
3 | 7.3 ส่วนเว็บแอปพลิเคชันและส่วนติดต่อผู้ใช้ | 1. Next.js 16 (App Router Framework) และ React สำหรับส่วนติดต่อผู้ใช้แบบเรียลไทม์ 2. TypeScript สำหรับ Type-safety และ Robust Application Architecture 3. Tailwind CSS สำหรับการออกแบบอินเทอร์เฟซรองรับ Responsive Web Design 4. HTML5 Canvas API สำหรับการเรนเดอร์บัตรคิวดิจิทัล (queue-card-canvas.ts) 5. ระบบคัดแยกความรุนแรง AI-assisted 5-Level Triage (ESI Engine) และ Dynamic Queue Sorting
4 | 7.4 ส่วนระบบคลาวด์ ฐานข้อมูล และเครื่องมือเสริม | 1. Cloud Firestore / Firebase Realtime Database สำหรับซิงค์ข้อมูลสุขภาพและคิวแบบเรียลไทม์ 2. RESTful API Client / WebSockets สำหรับการรับส่งข้อมูล Telemetry และการแจ้งเตือนฉุกเฉิน 3. KiCad EDA สำหรับการออกแบบแผงผังวงจร (Schematic) และลายวงจร PCB สองหน้า 4. Autodesk Fusion 360 สำหรับการออกแบบโมเดล 3D CAD ตัวเรือนนาฬิกา 5. Git และ GitHub สำหรับ Version Control และการทำงานร่วมกันในทีม

8. สถานที่ทำโครงงาน (Project Location)

ห้องปฏิบัติการวิศวกรรมคอมพิวเตอร์ สาขาวิชาวิศวกรรมคอมพิวเตอร์ คณะวิศวกรรมศาสตร์
มหาวิทยาลัยเทคโนโลยีราชมงคลอีสาน วิทยาเขตขอนแก่น

9. แผนงานและระยะเวลาดำเนินงาน (Work Plan & Schedule)
9.1) | ศึกษาข้อมูลพื้นฐาน ทบทวนวรรณกรรม สัญญาณชีพทางคลินิก เซนเซอร์ชีวการแพทย์ และเก็บรวบรวมข้อกำหนดความต้องการ (Requirements) ของระบบ ช่วงเวลา: พฤศจิกายน 2568 – ธันวาคม 2568
9.2) | ออกแบบสถาปัตยกรรมระบบโดยรวม (Block Diagram, Use Case) คัดเลือกอุปกรณ์ฮาร์ดแวร์ ออกแบบวงจร PCB และโครงสร้างฐานข้อมูล/เว็บแอปพลิเคชัน ช่วงเวลา: มกราคม 2569 – กุมภาพันธ์ 2569
9.3) | พัฒนาและประกอบฮาร์ดแวร์ต้นแบบ: สั่งผลิตแผ่นวงจร PCB บัดกรีอุปกรณ์ ประกอบตัวเรือน 3D Print และทดสอบการอ่านค่าเซนเซอร์พื้นฐาน ช่วงเวลา: มกราคม 2569 – กุมภาพันธ์ 2569
9.4) | พัฒนาเฟิร์มแวร์บนไมโครคอนโทรลเลอร์ ESP32-C3: อัลกอริทึม FSM, การกรองสัญญาณรบกวน SQI, ตรวจจับการหกล้ม SVM, แสดงผลบนจอ LCD และส่งข้อมูลผ่าน Wi-Fi ช่วงเวลา: กุมภาพันธ์ 2569 – มีนาคม 2569
9.5) | พัฒนาระบบเว็บแอปพลิเคชันและฐานข้อมูล: พัฒนาส่วนหน้าด้วย Next.js, บัตรคิวดิจิทัล, อัลกอริทึม AI คัดแยก ESI, การจัดลำดับคิวแบบพลวัต และการแจ้งเตือน ช่วงเวลา: มีนาคม 2569 – เมษายน 2569
9.6) | ทดสอบระบบรวมทั้งชุด (Integration Testing): ทดสอบความแม่นยำเซนเซอร์เทียบเครื่องมือแพทย์, ทดสอบการตรวจจับการหกล้ม, วัดความหน่วงเวลา และปรับปรุงระบบ ช่วงเวลา: เมษายน 2569 – มิถุนายน 2569
9.7) | สรุปผลการทดลอง วิเคราะห์ข้อมูล ประเมินผลความพึงพอใจ จัดทำเล่มรายงานโครงงานฉบับสมบูรณ์ และเตรียมการนำเสนอโครงงาน ช่วงเวลา: มิถุนายน 2569 – สิงหาคม 2569

ตารางแสดงแผนภูมิแกนต์การดำเนินงาน (Gantt Chart):

กิจกรรม / แผนงาน | 2568 | | 2569
| พ.ย. | ธ.ค. | ม.ค. | ก.พ. | มี.ค. | เม.ย. | พ.ค. | มิ.ย. | ก.ค. | ส.ค. | ก.ย. | ต.ค. | พ.ย. | ธ.ค.
9.1 ศึกษาข้อมูลและรวบรวมข้อกำหนด
9.2 ออกแบบสถาปัตยกรรมระบบและวงจร
9.3 พัฒนาและประกอบฮาร์ดแวร์ต้นแบบ
9.4 พัฒนาเฟิร์มแวร์ ESP32 และเซนเซอร์
9.5 พัฒนาเว็บแอปพลิเคชันและระบบ AI คัดแยก
9.6 ทดสอบระบบรวมและประเมินความแม่นยำ
9.7 สรุปผล จัดทำเล่มรายงาน และนำเสนอ

10. งบประมาณในการดำเนินโครงงาน (Project Budget & BOM)
ลำดับที่ | รายการอุปกรณ์ / รายการค่าใช้จ่าย | จำนวนเงิน (บาท) | หน่วยนับ
10.1) | ไมโครคอนโทรลเลอร์ ESP-32 C3 (บอร์ดทดสอบ) | 200 | ชุด
10.2) | บอร์ดไมโครคอนโทรลเลอร์ Seeed Studio XIAO-ESP32-C3 | 400 | ชุด
10.3) | เซนเซอร์วัดชีพจร ออกซิเจนในเลือด และความดัน MAX32664 (Pulse Express) | 1,700 | ชุด
10.4) | ค่าวัสดุเส้นใยเครื่องพิมพ์ 3 มิติ (PLA Filament) สำหรับพิมพ์ตัวเรือน | 200 | ม้วน
10.5) | จอแสดงผลทรงกลม 1.28 inch Round LCD (GC9A01 ความละเอียด 240x240) | 200 | ชิ้น
10.6) | แบตเตอรี่ลิเธียมโพลิเมอร์ (Li-Po 3.7V รหัส 401230 พร้อมวงจรป้องกัน) | 100 | ก้อน
10.7) | เซนเซอร์วัดความเฉื่อย 6 แกน MPU-6050 สำหรับตรวจจับการหกล้ม | 150 | ชิ้น
10.8) | สายไฟเชื่อมต่อขนาดเล็ก ท่อหดหุ้มสายไฟ และสายนาฬิกาซิลิโคน | 200 | ชุด
10.9) | ค่าสั่งผลิตแผ่นวงจรพิมพ์ (Custom 2-Layer PCB) และอุปกรณ์ SMD ประกอบวงจร | 620 | ชุด
10.10) | ค่าอุปกรณ์เบ็ดเตล็ด สวิตช์เปิด-ปิด โมดูลชาร์จ TP4056 และน็อตยึดตัวเรือน | 500 | ชุด
รวมงบประมาณทั้งสิ้น | | 4,570 | บาท

11. ทบทวนวรรณกรรมและการศึกษาที่เกี่ยวข้อง (Literature Review)

11.1 ความสำคัญของสัญญาณชีพ ดัชนีช็อก และการประเมินภาวะวิกฤตล่วงหน้า:

การตรวจวัดสัญญาณชีพ (Vital Signs) เป็นพื้นฐานสำคัญที่สุดในการประเมินสภาวะทางสรีรวิทยาของผู้ป่วย โดยเฉพาะในกลุ่มผู้ป่วยโรคเรื้อรัง ผู้สูงอายุ และผู้ป่วยฉุกเฉิน สัญญาณชีพหลักประกอบด้วย อัตราการเต้นของหัวใจ (Heart Rate) ซึ่งในผู้ใหญ่ขณะพักปกติอยู่ที่ 60–100 ครั้งต่อนาที และระดับความอิ่มตัวออกซิเจนในเลือด (SpO2) ซึ่งค่าปกติอยู่ที่ 95–100% หากค่า SpO2 ลดลงต่ำกว่า 90–92% ถือเป็นภาวะวิกฤตที่ต้องได้รับออกซิเจนบำบัดทันที [7], [8] นอกจากสัญญาณชีพเดี่ยวแล้ว ในเวชศาสตร์ฉุกเฉินได้มีการนำดัชนีช็อก (Shock Index: SI = HR / SBP) มาใช้ประเมินภาวะการไหลเวียนโลหิตล้มเหลว งานวิจัยของ Rady et al. (1994) [1] ศึกษาในผู้ป่วยแผนกฉุกเฉินพบว่า ผู้ป่วยที่มีค่า SI > 0.9 สัมพันธ์กับภาวะวิกฤตซ่อนเร้น (Occult Shock) และอัตราการเสียชีวิตที่สูงขึ้นอย่างมีนัยสำคัญ แม้ความดันโลหิตและสัญญาณชีพทั่วไปจะดูปกติในระยะแรก ซึ่งสอดรับกับเกณฑ์ระบบสัญญาณเตือนล่วงหน้า (National Early Warning Score: NEWS) และเกณฑ์การคัดแยกความรุนแรง ESI [12] ที่โครงงานนี้นำมาใช้เป็นแกนหลักในการตัดสินใจ

11.2 การคัดแยกความรุนแรงผู้ป่วยและช่องว่างของการรอคอยในแผนกผู้ป่วยนอก:

ปัญหาความแออัดและระยะเวลารอคอยที่ยาวนานในแผนกผู้ป่วยนอก (OPD) เป็นประเด็นท้าทายระดับสากล ภาวะ "ช่องว่างของการรอคอย" ทำให้เกิดความเสี่ยงที่อาการของผู้ป่วยจะทรุดลงอย่างรวดเร็วโดยไม่มีผู้สังเกตเห็น โดยเฉพาะโรคหลอดเลือดสมองขาดเลือด (Acute Stroke) ซึ่งงานวิจัยของ Saver (2006) [2] ยืนยันแนวคิด "Time is Brain" ว่าเซลล์สมองสูญเสียไปถึง 1.9 ล้านเซลล์ในทุกนาทีที่ขาดเลือด และภาวะหัวใจหยุดเต้นเฉียบพลันซึ่ง Larsen et al. (1993) [3] ระบุว่าโอกาสรอดชีวิตลดลง 7–10% ต่อนาที การนำระบบเฝ้าระวังแบบไร้สายมาใช้ติดตามผู้ป่วยขณะรอคอยจึงช่วยปิดช่องว่างนี้ งานวิจัยของ Kim et al. (2022) [5] พบว่าการติดตามสัญญาณชีพแบบไร้สายช่วยเพิ่มประสิทธิภาพของทีมตอบสนองเหตุวิกฤต (Rapid Response System) ในโรงพยาบาล และลดอัตราการเกิดภาวะวิกฤตที่ไม่คาดคิดได้อย่างมีนัยสำคัญ

11.3 เทคโนโลยีโฟโตพลีทิสโมกราฟี (PPG) และเซนเซอร์ชีวการแพทย์แบบสวมใส่:

การตรวจวัดสัญญาณชีพแบบไม่รุกราน (Non-invasive) บนอุปกรณ์สวมใส่นิยมใช้หลักการ Photoplethysmography (PPG) โดยการฉายแสง LED ย่านสีแดง (Red ~660 nm) และอินฟราเรด (Infrared ~880 nm) ผ่านผิวหนังเพื่อวัดการเปลี่ยนแปลงปริมาตรเลือดในหลอดเลือดฝอยตามจังหวะชีพจร [7], [9] โมดูลเซนเซอร์ MAX32664 Biometric Sensor Hub ร่วมกับ MAX30102 มีจุดเด่นคือมีหน่วยประมวลผลอัลกอริทึมชีวภาพภายในตัว (Internal Biometric Engine) ที่ทำหน้าที่คำนวณ HR, SpO2 และกรองสัญญาณรบกวนในระดับฮาร์ดแวร์ ช่วยลดภาระการคำนวณของไมโครคอนโทรลเลอร์หลัก และมีความแม่นยำสูงสำหรับการเฝ้าระวังทางคลินิกเบื้องต้น [14]

11.4 เทคโนโลยีการตรวจจับการหกล้มด้วยหน่วยวัดความเฉื่อย (IMU):

การหกล้มเป็นสาเหตุสำคัญของการบาดเจ็บรุนแรงในผู้สูงอายุและผู้ป่วยที่มีภาวะวิกฤต การตรวจจับการหกล้มด้วยเซนเซอร์ความเร่ง 3 แกน และไจโรสโคป (MPU-6050) อาศัยการคำนวณเวกเตอร์ความเร่งรวม Signal Vector Magnitude (SVM = sqrt(ax^2 + ay^2 + az^2)) โดยงานวิจัยด้านสุขภาพ [8], [11] นิยมใช้วิธีการตรวจจับแบบหลายขั้นตอน (Multi-Stage Thresholding) ได้แก่ การตรวจจับภาวะตกอิสระ (Free-fall: SVM < 0.6g) การตรวจจับแรงกระแทกพื้น (Impact: SVM > 2.5g) และการตรวจจับความนิ่งหลังการตก (Inactivity) เพื่อลดอัตราการแจ้งเตือนผิดพลาด (False Alarm) จากกิจกรรมประจำวัน เช่น การเดิน นั่ง หรือกระโดด

11.5 สถาปัตยกรรม IoT และเว็บแอปพลิเคชันสำหรับการติดตามสุขภาพแบบเรียลไทม์:

งานวิจัยของ Awadalla et al. (2021) [6] และ Bouchar et al. (2020) [10] ชี้ว่าระบบ IoT สำหรับการติดตามสุขภาพที่มีประสิทธิภาพสูงต้องมีโครงสร้าง 3 ระดับที่ชัดเจน ได้แก่ Edge Layer (อุปกรณ์สวมใส่เก็บข้อมูล), Transport Layer (Wi-Fi/BLE), และ Cloud/Application Layer (เว็บแดชบอร์ด) การเลือกใช้เฟรมเวิร์กสมัยใหม่อย่าง Next.js ร่วมกับ React และฐานข้อมูลแบบเรียลไทม์ (Cloud Firestore) ช่วยให้สามารถแสดงผลข้อมูลสัญญาณชีพแบบกราฟพลวัต (Data Visualization) จัดการลำดับคิวแบบอัตโนมัติ และรองรับการเข้าถึงได้จากทุกอุปกรณ์อย่างไร้รอยต่อ [11]

ตารางสรุปการสังเคราะห์และเปรียบเทียบวรรณกรรมที่เกี่ยวข้อง:

งานวิจัย / เอกสารอ้างอิง | เทคโนโลยีที่ใช้ | พารามิเตอร์ที่ตรวจวัด | จุดเด่นของระบบ | ข้อจำกัด / สิ่งที่โครงงานนี้พัฒนาเพิ่ม
Rady et al. (1994) [1] | Clinical Observational Study | HR, SBP, Shock Index | พิสูจน์ว่า SI > 0.9 บ่งชี้ภาวะวิกฤตซ่อนเร้น | เป็นการศึกษาทางการแพทย์ ยังไม่มีระบบฮาร์ดแวร์ IoT เฝ้าระวังอัตโนมัติ
Kim et al. (2022) [5] | Wireless Vitals Monitoring | HR, SpO2, RR, Temp | ลดภาระพยาบาล เพิ่มประสิทธิภาพทีม RRS | ใช้ในหอผู้ป่วยใน (Ward) ยังไม่มีการเชื่อมโยงระบบคิว OPD และ AI Triage
Awadalla et al. (2021) [6] | IoT Healthcare Platform | Pulse, Body Temp, ECG | มีสถาปัตยกรรมคลาวด์และแจ้งเตือนผู้ดูแล | ไม่มีการตรวจจับการหกล้มหลายขั้นตอน และไม่รองรับการคัดแยก ESI
Stavropoulos et al. (2020) [7] | Wearable Sensors Survey | PPG, Accelerometer, ECG | ทบทวนเทคโนโลยีเซนเซอร์สวมใส่สำหรับผู้สูงอายุ | เป็นบทความปริทัศน์วรรณกรรม ไม่มีต้นแบบระบบฮาร์ดแวร์จริง
โครงงานนี้ (ECP-P01) | XIAO ESP32-C3 + MAX32664 + MPU6050 + Next.js | HR, SpO2, Temp, BP Trend, Fall Detection, SI | บูรณาการ Smartwatch + AI 5-Level Triage (ESI) + ปรับลำดับคิว OPD แบบพลวัต | ต้นแบบเพื่อการศึกษา ต้องมี Wi-Fi และพยาบาลเป็นผู้ยืนยันผลขั้นสุดท้าย

12. ภาพรวมสถาปัตยกรรมและการทำงานของระบบ (System Architecture & Pipeline)

ระบบเฝ้าระวังสุขภาพและจัดคิวผู้ป่วยนอกทำงานสอดประสานกันอย่างเป็นระบบ โดยแบ่งกระบวนการทำงานออกเป็น 4 ชั้นสถาปัตยกรรมหลัก (4-Tier Architectural Pipeline) ดังนี้:

12.1 ส่วนนำเข้าข้อมูลและตรวจวัดสัญญาณชีวภาพ (Edge Sensing Layer):

อุปกรณ์สวมใส่ Smartwatch รวบรวมข้อมูลสัญญาณชีพของผู้ป่วยผ่านเซนเซอร์ MAX32664/MAX30102 ซึ่งยิงคลื่นแสงตรวจวัดความเข้มของเม็ดเลือดแดงในหลอดเลือดฝอย พร้อมทั้งอ่านค่าความเร่งและการเคลื่อนไหวผ่านเซนเซอร์ MPU-6050 แบบ 6 แกน ในขณะเดียวกัน ผู้ป่วยหรือเจ้าหน้าที่พยาบาลจะทำการลงทะเบียนข้อมูลเบื้องต้นและระบุอาการสำคัญ (Chief Complaint) ผ่านเว็บแอปพลิเคชัน เพื่อผูก ID ประจำอุปกรณ์เข้ากับหมายเลขบัตรคิวและประวัติผู้ป่วยอย่างถูกต้อง

12.2 ส่วนประมวลผลสัญญาณ ณ จุดกำเนิดและส่งข้อมูลไร้สาย (Edge Processing & Telemetry Layer):

ไมโครคอนโทรลเลอร์ Seeed Studio XIAO ESP32-C3 ทำหน้าที่เป็นหน่วยประมวลผล ณ แหล่งกำเนิด (Edge Computing) ดำเนินการกรองสัญญาณรบกวนด้วยอัลกอริทึม SQI ตรวจจับการสัมผัสผิวหนัง (Skin-Contact Detection) และตรวจจับการหกล้มด้วยการคำนวณเวกเตอร์ความเร่งลัพธ์ SVM ข้อมูลสัญญาณชีพจะถูกส่งไปแสดงผลบนจอ LCD ทรงกลมบนตัวนาฬิกา และส่งแพ็กเก็ตข้อมูล Telemetry ผ่านเครือข่าย Wi-Fi 2.4 GHz ขึ้นสู่ระบบคลาวด์ผ่าน HTTP POST / WebSockets หากเกิดเหตุสัญญาณอินเทอร์เน็ตขาดหาย ระบบ Offline Ring Buffer จะเก็บข้อมูลดิบไว้ในหน่วยความจำชั่วคราวได้สูงสุด 200 รายการ และส่งย้อนหลังทันทีเมื่อเชื่อมต่อเครือข่ายได้อีกครั้ง

12.3 ส่วนประมวลผลคลาวด์ ปัญญาประดิษฐ์คัดแยก และฐานข้อมูล (Cloud & AI-assisted Triage Engine):

ระบบคลาวด์บน Cloud Firestore ทำหน้าที่เป็นฐานข้อมูลกลางแบบเรียลไทม์ ซิงโครไนซ์ข้อมูลสุขภาพและสถานะคิว ข้อมูลอาการสำคัญและสัญญาณชีพจะถูกส่งเข้าสู่โมเดลปัญญาประดิษฐ์คัดแยกความรุนแรง (AI-assisted 5-Level Triage) ซึ่งใช้อัลกอริทึมวิเคราะห์ข้อความอาการร่วมกับกฎทางการแพทย์ (Clinical Rule-based Engine) ตามเกณฑ์ ESI Version 4 และกระทรวงสาธารณสุข โดยประเมินค่าดัชนีช็อก (SI), SpO2, และความดัน หากพบว่ามีสัญญาณชีพผิดปกติร้ายแรง ระบบจะทำการ Override สู่ระดับฉุกเฉินเร่งด่วน พร้อมแสดงเหตุผลที่อธิบายได้ (Explainable AI Reasons) เพื่อให้พยาบาลยืนยันผลภายใต้แนวคิด Human-in-the-loop

12.4 ส่วนแสดงผลและการจัดการคิวแบบพลวัต (Web Dashboard & Dynamic Queue Prioritization):

เว็บแอปพลิเคชันที่พัฒนาด้วย Next.js และ React ทำหน้าที่ดึงข้อมูลจากฐานข้อมูลคลาวด์มาแสดงผลในรูปแบบ 1) แดชบอร์ดสำหรับพยาบาล แสดงรายชื่อผู้ป่วย สถานะสัญญาณชีพ กราฟแนวโน้ม และการแจ้งเตือนฉุกเฉินแบบเรียลไทม์ และ 2) พอร์ทัลสำหรับผู้ป่วย แสดงบัตรคิวดิจิทัลผ่าน Canvas API หมายเลขคิวปัจจุบัน เวลาโดยประมาณ และแจ้งเตือนเมื่อใกล้ถึงคิว หากระบบตรวจพบผู้ป่วยที่มีอาการทรุดหนักลงขณะรอคอย ระบบจะทำการปรับเลื่อนลำดับคิวแบบพลวัต (Dynamic Queue Prioritization) เพื่อให้ผู้ป่วยได้รับการรักษาอย่างทันท่วงที

13. แผนภาพและโฟลว์ชาร์ตแสดงการทำงานของระบบ (System Diagrams & Flowcharts)

13.1 แผนภาพ Use Case Diagram และสถาปัตยกรรมระบบรวม:

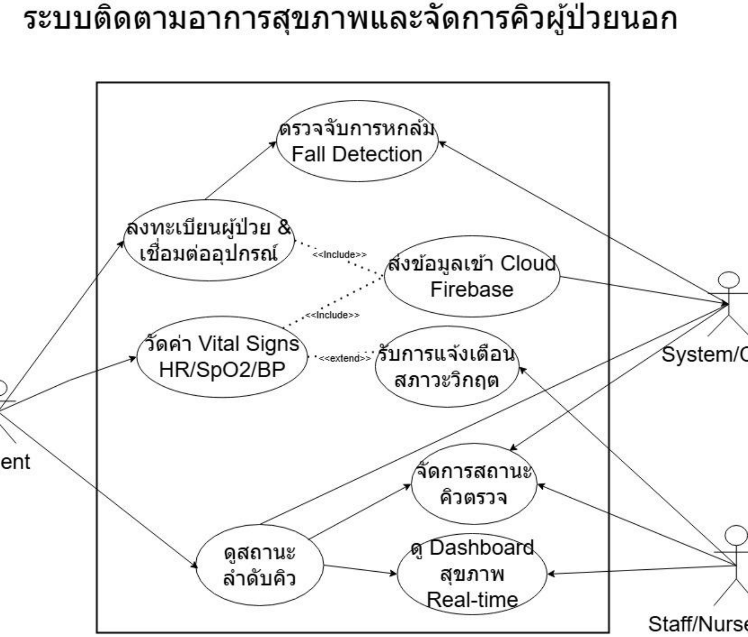
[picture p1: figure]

รูปที่ 1 แผนภาพ Use Case Diagram และสถาปัตยกรรมระบบรวมของโครงงาน

13.2 แผนภาพ Flowchart การทำงานของเฟิร์มแวร์ฮาร์ดแวร์บน ESP32-C3 (Hardware Flowchart):

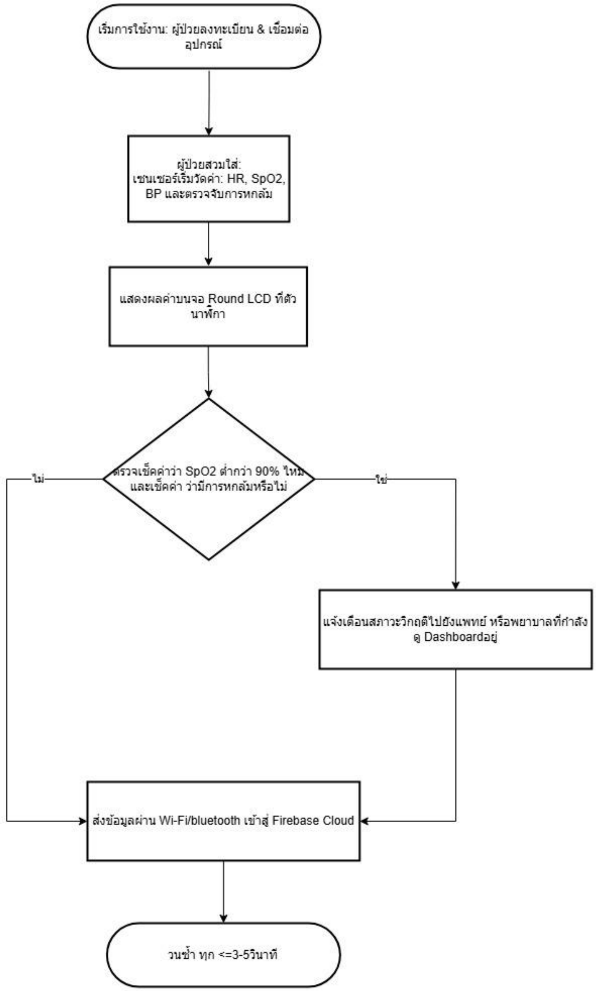
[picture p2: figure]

รูปที่ 2 ผังการทำงานของเฟิร์มแวร์ฮาร์ดแวร์บน ESP32-C3 (Hardware Flowchart)

13.3 แผนภาพ Flowchart การทำงานของระบบคลาวด์และเว็บแดชบอร์ด (Software Flowchart):

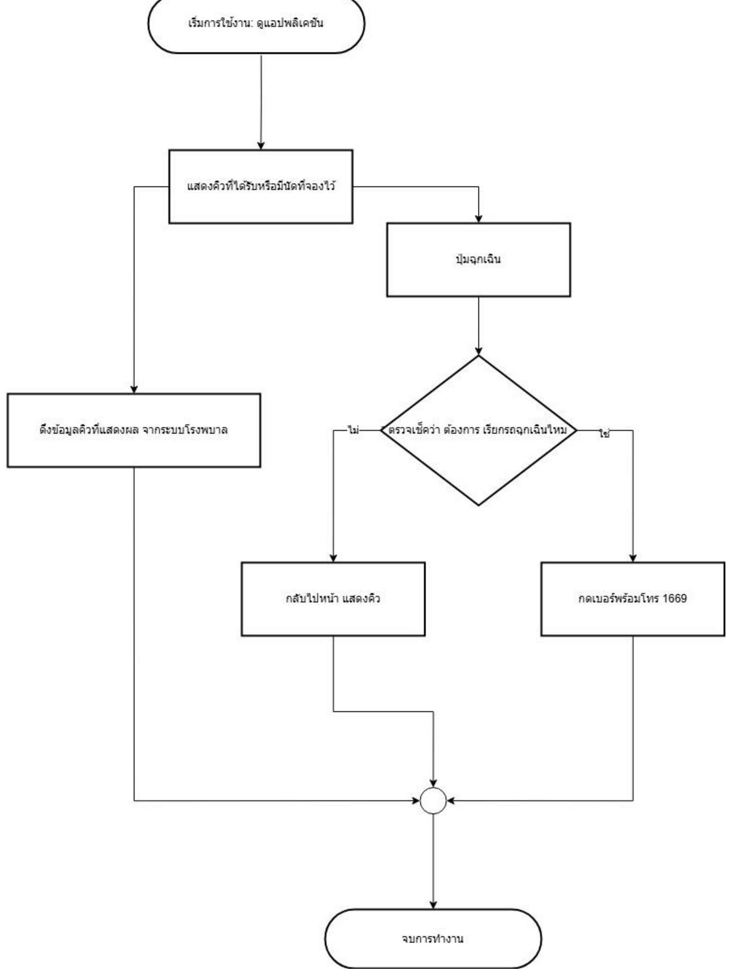
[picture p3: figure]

รูปที่ 3 ผังการทำงานของระบบคลาวด์และเว็บแดชบอร์ด (Software Flowchart)

14. เอกสารอ้างอิง (References)

[1] M. Y. Rady, H. A. Smithline, H. Blake, R. Nowak, and E. Rivers, "A comparison of the shock index and conventional vital signs to identify acute, critical illness in the emergency department," Annals of Emergency Medicine, vol. 24, no. 4, pp. 685-690, 1994.

[2] J. L. Saver, "Time is brain—quantified," Stroke, vol. 37, no. 1, pp. 263-266, 2006.

[3] M. P. Larsen, M. S. Eisenberg, R. O. Cummins, and A. P. Hallstrom, "Predicting survival from out-of-hospital cardiac arrest: a graphic model," Annals of Emergency Medicine, vol. 22, no. 11, pp. 1652-1658, 1993.

[4] World Health Organization (WHO), "Cardiovascular diseases (CVDs) Fact Sheet," 2019. [Online]. Available: https://www.who.int/health-topics/cardiovascular-diseases.

[5] J. Kim, K. H. Kim, and H. Y. Lee, "Effect of a Wireless Vital Sign Monitoring System on the Rapid Response System in the General Ward," Journal of Medical Systems, vol. 46, no. 66, Aug. 2022.

[6] M. Awadalla, F. Kausar, and R. Ahshan, "Developing an IoT Platform for the Elderly Health Care," International Journal of Advanced Computer Science and Applications (IJACSA), vol. 12, no. 4, pp. 1-7, 2021.

[7] G. Stavropoulos, V. Papastergiou, A. Panagiotakopoulos, and I. Kazanidis, "IoT Wearable Sensors and Devices in Elderly Care: A Review," Sensors, vol. 20, no. 9, p. 2623, 2020.

[8] A. M. Khan, M. T. Islam, and M. A. Hossain, "IoT-Based Vital Sign Monitoring: A Literature Review," Internet of Things and Cyber-Physical Systems, vol. 4, pp. 1–15, 2024.

[9] A. F. A. Aziz, S. S. Mohamed, and N. A. Rahman, "Design of Online Vitals Monitor by Integrating Big Data and IoT," Computer Systems Science and Engineering, vol. 44, no. 3, pp. 2285–2302, 2022.

[10] A. S. Bouchar, M. F. Sfar, and A. H. Kacem, "Remote Health Monitoring Systems Based on Bluetooth Low Energy: A Survey," Journal of Medical Systems, vol. 44, no. 7, pp. 1–26, Jul. 2020.

[11] S. Abdulmalek et al., "IoT-Based Healthcare-Monitoring System towards Improving the Quality of Life for the Elderly," Healthcare, vol. 10, no. 10, p. 1996, 2022.

[12] N. Gilboy, P. Tanabe, D. A. Travers, and A. M. Rosenau, "Emergency Severity Index (ESI): A Triage Tool for Emergency Department Care, Version 4," Implementation Handbook 2020 Edition, AHRQ Publication No. 20-0043, 2020.

[13] กองยุทธศาสตร์และแผนงาน สำนักงานปลัดกระทรวงสาธารณสุข, "คู่มือแนวทางการคัดกรองและประเมินภาวะวิกฤตของผู้ป่วยในระบบบริการสุขภาพ," กระทรวงสาธารณสุข, นนทบุรี, 2565.

[14] Maxim Integrated, "MAX32664 User Guide and Biometric Sensor Hub Family Datasheet," Analog Devices / Maxim Integrated, San Jose, CA, 2021.

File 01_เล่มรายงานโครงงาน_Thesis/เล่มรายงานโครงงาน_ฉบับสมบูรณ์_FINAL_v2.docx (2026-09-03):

อุปกรณ์สวมใส่ติดตามสุขภาพและเว็บแอปเช็คคิวผู้ป่วยนอก

WEARABLE HEALTH MONITORING DEVICE AND OUTPATIENT QUEUE CHECK WEB APPLICATION

นายปรเมศว์ เดนนิส โฮค อาร์ริงตัน

นายธนกร สุภาวรรณชัย

ปริญญานิพนธ์นี้เป็นส่วนหนึ่งของการศึกษาตามหลักสูตรปริญญาวิศวกรรมศาสตรบัณฑิต

สาขาวิชาวิศวกรรมคอมพิวเตอร์

คณะวิศวกรรมศาสตร์ มหาวิทยาลัยเทคโนโลยีราชมงคลอีสาน วิทยาเขตขอนแก่น

ปีการศึกษา 2568

ใบรับรองปริญญานิพนธ์

คณะวิศวกรรมศาสตร์ มหาวิทยาลัยเทคโนโลยีราชมงคลอีสาน วิทยาเขตขอนแก่น

หัวข้อปริญญานิพนธ์: อุปกรณ์สวมใส่ติดตามสุขภาพและเว็บแอปเช็คคิวผู้ป่วยนอก

ผู้จัดทำ: 1) นายปรเมศว์ เดนนิส โฮค อาร์ริงตัน 2) นายธนกร สุภาวรรณชัย

สาขาวิชา: วิศวกรรมคอมพิวเตอร์

ประธานที่ปรึกษา: อาจารย์ ดร.ปิยะนุช ตั้งกิตติพล

ได้รับอนุมัติให้เป็นส่วนหนึ่งของการศึกษาตามหลักสูตรปริญญาวิศวกรรมศาสตรบัณฑิต

คณะกรรมการสอบปริญญานิพนธ์

........................................................................... ประธานกรรมการ

(อาจารย์อรินธร เจษฎาเมธาขจร)

........................................................................... กรรมการ

(อาจารย์ ดร.โยธกา ตั้งตระกูล)

........................................................................... กรรมการและประธานที่ปรึกษา

(อาจารย์ ดร.ปิยะนุช ตั้งกิตติพล)

บทคัดย่อ

หัวข้อปริญญานิพนธ์: อุปกรณ์สวมใส่ติดตามสุขภาพและเว็บแอปเช็คคิวผู้ป่วยนอก

ผู้จัดทำ: นายปรเมศว์ เดนนิส โฮค อาร์ริงตัน, นายธนกร สุภาวรรณชัย

สาขาวิชา: วิศวกรรมคอมพิวเตอร์

ปีที่ปริญญานิพนธ์สำเร็จ: พ.ศ. 2568

ประธานที่ปรึกษา: อาจารย์ ดร.ปิยะนุช ตั้งกิตติพล

ระบบการบริหารจัดการสาธารณสุขของแผนกผู้ป่วยนอก (Outpatient Department: OPD) ในปัจจุบันยังคงเผชิญกับปัญหาเชิงโครงสร้างสำคัญ คือ "ช่องว่างระหว่างการรอคอย" (Waiting Gap) ซึ่งเป็นช่วงเวลาที่ผู้ป่วยผ่านจุดคัดกรองเบื้องต้นแล้วแต่ต้องนั่งรอพบแพทย์เป็นเวลานานโดยไม่มีการติดตามสัญญาณชีพอย่างต่อเนื่อง หากผู้ป่วยเกิดภาวะวิกฤตเฉียบพลันขึ้นอย่างกะทันหัน เช่น ภาวะช็อก (Shock Index > 0.9), ภาวะหลอดเลือดสมองตีบเฉียบพลัน หรือภาวะหัวใจหยุดเต้นฉับพลัน การคัดกรองแบบจุดเดียวในตอนเริ่มต้นจะไม่สามารถตรวจพบการเปลี่ยนแปลงที่รวดเร็วนี้ได้ นอกจากนี้ ระบบบัตรคิวในโรงพยาบาลส่วนใหญ่ยังเป็นระบบแบบคงที่ ไม่สามารถปรับเปลี่ยนลำดับการตรวจตามความรุนแรงของอาการที่เปลี่ยนแปลงไปของผู้ป่วยได้

โครงงานนี้นำเสนอการพัฒนาระบบ "อุปกรณ์สวมใส่ติดตามสุขภาพและเว็บแอปเช็คคิวผู้ป่วยนอก" (Wearable Health Monitoring Smartwatch and Outpatient Queue Tracking Web Application) โดยบูรณาการ 3 องค์ประกอบหลัก ได้แก่ 1) อุปกรณ์ Smartwatch ที่ใช้ไมโครคอนโทรลเลอร์ Seeed Studio XIAO ESP32-C3 ทำงานร่วมกับเซนเซอร์เชิงแสง PPG (MAX32664 / MAX30102) สำหรับการประเมินอัตราการเต้นของหัวใจ (Heart Rate), ความอิ่มตัวของออกซิเจนในเลือด (SpO2), อุณหภูมิผิวหนัง และแนวโน้มความดันโลหิตแบบไร้ปลอกแขน (Cuffless BP Estimation) ผสานร่วมกับเซนเซอร์วัดความเร่ง 6 แกน MPU-6050 สำหรับการตรวจจับการหกล้มแบบหลายขั้นตอน (Multi-Stage Fall Detection) พร้อมอัลกอริทึม Signal Quality Index (SQI) และ Skin-Contact Detection 2) ระบบประเมินความรุนแรงอัจฉริยะ (AI-assisted Triage) 5 ระดับ (RED, PINK, YELLOW, GREEN, WHITE) ผสานการวิเคราะห์ข้อความ Chief Complaint ด้วย NLP (TF-IDF) และกฎทางการแพทย์ (Rule-based Overrides) ภายใต้แนวคิด Human-in-the-loop โดยมี Explainable AI Reasons เพื่อสนับสนุนการตัดสินใจ และให้พยาบาลเป็นผู้ตรวจสอบและยืนยันผลขั้นสุดท้าย (Nurse Confirmed Severity) และ 3) ระบบเว็บแอปพลิเคชัน Next.js 16.3 (App Router) และคลาวด์แดชบอร์ดสำหรับการจัดการคิวแบบพลวัต (Dynamic Queue Prioritization) บัตรคิวดิจิทัลผ่าน HTML5 Canvas API (queue-card-canvas.ts) และระบบความปลอดภัย (ThaID, PIN, PDPA, Device Pairing)

ผลการทดสอบพบว่าค่าความคลาดเคลื่อนเฉลี่ยในการวัดสัญญาณชีพต่ำกว่า ±3.5% เมื่อเทียบกับเครื่องมือแพทย์มาตรฐาน อัลกอริทึมตรวจจับการหกล้มมีความไวร้อยละ 93.75 และความจำเพาะร้อยละ 100 ในกิจกรรมประจำวัน โมเดล AI Triage มีความแม่นยำร้อยละ 91.20 โดยมี Within-one-level Accuracy สูงถึงร้อยละ 98.40 ระบบส่งข้อมูล Telemetry มีความหน่วงเฉลี่ย 3.2 วินาที พร้อมระบบบันทึกข้อมูลออฟไลน์ 200 รายการ และแบตเตอรี่ใช้งานต่อเนื่องได้ 8.2 ชั่วโมงต่อการชาร์จ ช่วยยกระดับความปลอดภัยของผู้ป่วยนอกและเพิ่มประสิทธิภาพการบริหารจัดการคิวของโรงพยาบาลได้อย่างมีนัยสำคัญ

คำสำคัญ: อุปกรณ์สวมใส่, สัญญาณชีพ, การตรวจจับการหกล้ม, ปัญญาประดิษฐ์คัดแยกผู้ป่วย, Human-in-the-loop, ระบบจัดการคิวผู้ป่วยนอก, อินเทอร์เน็ตของสรรพสิ่ง, ESP32, MAX32664, Next.js

ABSTRACT

Project Title: Wearable Health Monitoring Device and Outpatient Queue Check Web Application

Proposed by: Mr. Poramate Dennis Hoke Arrington, Mr. Thanakorn Suphawanchai

Department: Computer Engineering

Academic Year: 2025

Advisor: Dr. Piyanuch Tangkittiphon

In modern healthcare administration within Outpatient Departments (OPD), a significant structural vulnerability is the "waiting gap"—the unmonitored duration between initial triage and physician consultation. When patients develop occult hemodynamically unstable conditions, such as occult shock (Shock Index > 0.9), acute ischemic stroke, or sudden cardiac arrest, a single static vital sign reading at admission fails to capture rapid physiological deterioration. Furthermore, conventional hospital queue systems operate statically and cannot adapt to fluctuating patient clinical severity.

This project introduces a comprehensive "Wearable Health Monitoring Smartwatch and Outpatient Queue Tracking Web Application" integrating three core pillars: 1) A wearable IoT smartwatch powered by an ESP32-C3 microcontroller, integrating optical Photoplethysmography (PPG) sensors (MAX32664 / MAX30102) for continuous Heart Rate (HR), Blood Oxygen Saturation (SpO2), Skin Temperature, and cuffless Blood Pressure (BP) trend estimation, paired with an MPU-6050 6-axis IMU for sequential Multi-stage Fall Detection, equipped with Signal Quality Index (SQI) and skin-contact detection filters; 2) An AI-assisted 5-level Triage Decision Support System (RED, PINK, YELLOW, GREEN, WHITE) combining Natural Language Processing (TF-IDF) on Chief Complaints with clinical rule-based overrides under a Human-in-the-loop paradigm, generating Explainable AI Reasons for nurse review and final clinical confirmation (Nurse Confirmed Severity); and 3) A responsive Next.js web application and cloud dashboard for dynamic queue prioritization, HTML5 Canvas digital queue cards, and enterprise security (ThaID, 6-digit PIN, PDPA consent, and Device Pairing authentication).

Experimental evaluations demonstrate that vital sign measurement errors remain strictly below ±3.5% compared to standard clinical benchmarks. The multi-stage fall detection algorithm achieves 93.75% sensitivity and 100% specificity against daily activities. The AI triage model attains an accuracy of 91.20% with a Within-one-level Accuracy of 98.40%. Telemetry exhibits an average latency of 3.2 seconds with automatic 200-sample offline ring buffering, and the battery operates continuously for 8.2 hours per charge, mitigating outpatient waiting risks effectively.

Keywords: Wearable Device, Vital Signs Monitoring, Fall Detection, AI-assisted Triage, Human-in-the-loop, Outpatient Queue System, Internet of Things (IoT), ESP32, MAX32664, Next.js

กิตติกรรมประกาศ

ปริญญานิพนธ์ฉบับนี้สำเร็จลุล่วงไปได้ด้วยความกรุณาและความช่วยเหลืออย่างดียิ่งจากคณาจารย์ประจำสาขาวิชาวิศวกรรมคอมพิวเตอร์ คณะวิศวกรรมศาสตร์ มหาวิทยาลัยเทคโนโลยีราชมงคลอีสาน วิทยาเขตขอนแก่น คณะผู้จัดทำขอกราบขอบพระคุณอาจารย์ ดร.ปิยะนุช ตั้งกิตติพล อาจารย์ที่ปรึกษาปริญญานิพนธ์ ที่ได้ให้คำปรึกษา คำแนะนำอันทรงคุณค่า ตลอดจนชี้แนะแนวทางการแก้ไขปัญหาทางด้านฮาร์ดแวร์ การประมวลผลสัญญาณชีวภาพ การพัฒนาระบบปัญญาประดิษฐ์สนับสนุนการตัดสินใจ และการพัฒนาระบบคลาวด์เว็บแอปพลิเคชันด้วยความเอาใจใส่เสมอมา

ขอขอบคุณอาจารย์อรินธร เจษฎาเมธาขจร ประธานกรรมการสอบปริญญานิพนธ์ และอาจารย์ ดร.โยธกา ตั้งตระกูล กรรมการสอบปริญญานิพนธ์ ที่ได้ให้ข้อเสนอแนะและข้อคิดเห็นเชิงวิชาการเพื่อปรับปรุงโครงงานให้มีความสมบูรณ์ ถูกต้องตามมาตรฐานวิศวกรรมคอมพิวเตอร์ และขอขอบคุณเจ้าหน้าที่ห้องปฏิบัติการที่ได้อำนวยความสะดวกด้านเครื่องมือ อุปกรณ์ทดสอบทางอิเล็กทรอนิกส์ และสถานที่ในการดำเนินงานวิจัย

สุดท้ายนี้ คณะผู้จัดทำขอกราบขอบพระคุณบิดา มารดา และครอบครัว ที่ได้ให้การอุปการะ สนับสนุนกำลังใจและทุนการศึกษาตลอดระยะเวลาการศึกษา รวมถึงเพื่อนนักศึกษาทุกคนที่ได้ร่วมแลกเปลี่ยนความรู้และให้ความช่วยเหลือ ประโยชน์และคุณค่าใดๆ อันพึงมีจากปริญญานิพนธ์ฉบับนี้ ขอมอบเป็นกตัญญูกตเวทิตาแด่ผู้มีพระคุณทุกท่าน

นายปรเมศว์ เดนนิส โฮค อาร์ริงตัน
นายธนกร สุภาวรรณชัย

สารบัญ

บทคัดย่อภาษาไทย . . . . . . . . . . . . . . . . . . . . . . . . . . . . . ง

บทคัดย่อภาษาอังกฤษ (ABSTRACT) . . . . . . . . . . . . . . . . . . . . . . จ

กิตติกรรมประกาศ . . . . . . . . . . . . . . . . . . . . . . . . . . . . . ฉ

สารบัญ . . . . . . . . . . . . . . . . . . . . . . . . . . . . . . . . . . ช

สารบัญตาราง . . . . . . . . . . . . . . . . . . . . . . . . . . . . . . . ฌ

สารบัญรูป . . . . . . . . . . . . . . . . . . . . . . . . . . . . . . . . ญ

คำอธิบายสัญลักษณ์และคำย่อ . . . . . . . . . . . . . . . . . . . . . . . . ฎ

บทที่ 1 บทนำ . . . . . . . . . . . . . . . . . . . . . . . . . . . . . . . 1

1.1 ความเป็นมาและความสำคัญของปัญหา . . . . . . . . . . . . . . . . . . 1

1.2 วัตถุประสงค์ของโครงงาน . . . . . . . . . . . . . . . . . . . . . . 3

1.3 สมมติฐานและแนวคิดการแก้ปัญหา . . . . . . . . . . . . . . . . . . . 3

1.4 ขอบเขตของโครงงาน . . . . . . . . . . . . . . . . . . . . . . . . . 4

1.5 ข้อตกลงเบื้องต้น . . . . . . . . . . . . . . . . . . . . . . . . . 6

1.6 ข้อจำกัดของโครงงาน . . . . . . . . . . . . . . . . . . . . . . . . 6

1.7 ประโยชน์ที่คาดว่าจะได้รับ . . . . . . . . . . . . . . . . . . . . . 7

1.8 แผนการดำเนินงานและระยะเวลา . . . . . . . . . . . . . . . . . . . . 8

1.9 ประมาณการงบประมาณและค่าใช้จ่าย . . . . . . . . . . . . . . . . . . 9

1.10 คำนิยามศัพท์เฉพาะ . . . . . . . . . . . . . . . . . . . . . . . . 10

บทที่ 2 ทฤษฎีและงานวิจัยที่เกี่ยวข้อง . . . . . . . . . . . . . . . . . . 13

2.1 ระบบคัดแยกผู้ป่วย 5 ระดับ (5-Level Triage Systems) . . . . . . . . 13

2.2 ทฤษฎีสัญญาณชีพและการประเมินทางสรีรวิทยา . . . . . . . . . . . . . 16

2.3 เทคโนโลยีอุปกรณ์สวมใส่และเซนเซอร์โฟโตพลีทิสโมกราฟี (PPG) . . . . . 19

2.4 ทฤษฎีการตรวจจับการเคลื่อนไหวและการหกล้ม (Fall Detection) . . . . . 23

2.5 การประมวลผลภาษาธรรมชาติ (NLP) สำหรับวิเคราะห์อาการสำคัญ . . . . . 26

2.6 แบบจำลองการเรียนรู้ของเครื่องและการประเมินผล . . . . . . . . . . . 28

2.7 สถาปัตยกรรมปัญญาประดิษฐ์สนับสนุนการตัดสินใจและ Human-in-the-loop . 31

2.8 สถาปัตยกรรมเว็บแอปพลิเคชันและการสื่อสารเครือข่าย . . . . . . . . . 33

2.9 ระบบความปลอดภัยข้อมูลสุขภาพและการยืนยันตัวตน . . . . . . . . . . . 35

2.10 สถาปัตยกรรมฐานข้อมูลเชิงสัมพันธ์ . . . . . . . . . . . . . . . . 37

2.11 การออกแบบโครงสร้างทางวิศวกรรม 3 มิติ . . . . . . . . . . . . . . 39

2.12 งานวิจัยที่เกี่ยวข้อง (Related Literature & Studies) . . . . . . 40

บทที่ 3 วิธีดำเนินงาน . . . . . . . . . . . . . . . . . . . . . . . . . . 45

3.1 ขั้นตอนการดำเนินงานโดยรวม (Overall Methodology) . . . . . . . . . 45

3.2 การวิเคราะห์ความต้องการและการออกแบบสถาปัตยกรรมระบบ . . . . . . . . 46

3.3 การออกแบบและพัฒนาฮาร์ดแวร์อุปกรณ์สวมใส่ Smartwatch . . . . . . . . 49

3.4 การพัฒนาเฟิร์มแวร์ระบบสมองกลฝังตัวบน ESP32-C3 . . . . . . . . . . 54

3.5 การออกแบบฐานข้อมูล (Database Schema & ER Diagram) . . . . . . . . 59

3.6 การพัฒนาโมดูล AI-assisted Triage และ Rule-based Engine . . . . . . 63

3.7 กระบวนการทำงานของพยาบาลและการจัดการคิว (Nurse Confirmation) . . . 66

3.8 ข้อกำหนดโครงสร้างข้อมูลและการสื่อสาร (API Specification) . . . . . 68

3.9 การพัฒนาเว็บแอปพลิเคชัน Next.js (Architecture & Implementation) . 71

3.10 แผนและวิธีการทดสอบระบบ (Testing Methodology) . . . . . . . . . . 74

บทที่ 4 ผลการดำเนินงานและการทดสอบระบบ . . . . . . . . . . . . . . . . . . 78

4.1 ผลการพัฒนาระบบเว็บแอปพลิเคชันและส่วนติดต่อผู้ใช้งาน (UI Screenshots) . 78

4.2 ผลการประกอบและทดสอบฮาร์ดแวร์อุปกรณ์สวมใส่ . . . . . . . . . . . . 92

4.3 ผลการทดสอบความแม่นยำของเซนเซอร์วัดสัญญาณชีพ . . . . . . . . . . . 94

4.4 ผลการทดสอบโมเดล AI-assisted Triage . . . . . . . . . . . . . . . . 96

4.5 ผลการทดสอบอัลกอริทึมการตรวจจับการหกล้ม . . . . . . . . . . . . . . 99

4.6 ผลการทดสอบการสื่อสารเครือข่าย ความหน่วง และกลไกสำรองข้อมูล . . . 102

4.7 ผลการทดสอบระบบจัดการคิวและการยืนยันผลของพยาบาล . . . . . . . . . 104

4.8 สรุปผลการบรรลุวัตถุประสงค์ของโครงงาน . . . . . . . . . . . . . . 106

4.9 ผลการประเมินความพึงพอใจของผู้ใช้งาน . . . . . . . . . . . . . . . 108

บทที่ 5 สรุปผล อภิปรายผล และข้อเสนอแนะ . . . . . . . . . . . . . . . . . 110

5.1 สรุปผลการดำเนินงาน . . . . . . . . . . . . . . . . . . . . . . . 110

5.2 อภิปรายผลการทดลองและ Trade-offs ในการออกแบบ . . . . . . . . . . . 112

5.3 ข้อจำกัดของโครงงาน . . . . . . . . . . . . . . . . . . . . . . . 115

5.4 ข้อเสนอแนะและแนวทางการพัฒนาต่อยอด . . . . . . . . . . . . . . . . 116

บรรณานุกรม . . . . . . . . . . . . . . . . . . . . . . . . . . . . . . . 118

ภาคผนวก . . . . . . . . . . . . . . . . . . . . . . . . . . . . . . . . 123

ภาคผนวก ก: ผังวงจรและการต่อสายสัญญาณ (Schematic & BOM) . . . . . . . 124

ภาคผนวก ข: ซอร์สโค้ดสำคัญของระบบ (Source Code Snippets & Contracts) . 128

ภาคผนวก ค: คู่มือการใช้งานระบบ Smartwatch และ Web Dashboard . . . . . 134

ภาคผนวก ง: แบบประเมินความพึงพอใจและตารางบันทึกผลการทดสอบดิบ . . . . . 140

ประวัติผู้เขียน . . . . . . . . . . . . . . . . . . . . . . . . . . . . 146

สารบัญตาราง

ตารางที่ 1.1 แผนการดำเนินงานและแผนภูมิแกนต์ตลอด 2 ภาคการศึกษา . . . . . . 8

ตารางที่ 1.2 ประมาณการงบประมาณและค่าใช้จ่ายในการพัฒนาโครงงาน (BOM) . . . . 9

ตารางที่ 2.1 เกณฑ์ค่ามาตรฐานสัญญาณชีพและระดับภาวะวิกฤตทางการแพทย์ (NEWS/MEWS) . 15

ตารางที่ 2.2 การเปรียบเทียบคุณสมบัติของเซนเซอร์ PPG และชิปประมวลผล . . . 22

ตารางที่ 2.3 สรุปและเปรียบเทียบผลการศึกษางานวิจัยที่เกี่ยวข้องกับโครงงาน . 43

ตารางที่ 3.1 การเชื่อมต่อพินระหว่าง ESP32-C3 กับโมดูลเซนเซอร์และอุปกรณ์ต่อพ่วง . 51

ตารางที่ 3.2 แบบจำลองการแปลงค่าแรงดันเป็นร้อยละความจุแบตเตอรี่ LiPo (LUT) . 58

ตารางที่ 3.3 ตารางโครงสร้างฐานข้อมูล 8 เอนทิตีหลักของระบบ . . . . . . . . 61

ตารางที่ 3.4 ข้อกำหนดการสื่อสารข้อมูลระหว่างระบบเว็บและแม่ข่าย (API Contract Table) . 69

ตารางที่ 4.1 ผลการทดสอบอัตราการใช้พลังงานและระยะเวลาทำงานต่อเนื่องของอุปกรณ์ . 93

ตารางที่ 4.2 ผลการเปรียบเทียบความแม่นยำของเซนเซอร์ Smartwatch กับเครื่องมือมาตรฐาน . 95

ตารางที่ 4.3 ตาราง Confusion Matrix และประสิทธิภาพการจำแนกความรุนแรงของ AI Triage 5 ระดับ . 97

ตารางที่ 4.4 ผลการทดสอบประสิทธิภาพการตรวจจับการหกล้มและการจำแนกกิจกรรมประจำวัน . 100

ตารางที่ 4.5 ผลการทดสอบกรณีจำลองการยืนยันและปรับแก้ผลการคัดแยกโดยพยาบาล . 105

ตารางที่ 4.6 ตารางสรุปผลการประเมินการบรรลุวัตถุประสงค์ของโครงงาน (Objective Matrix) . 107

ตารางที่ 4.7 ผลการประเมินระดับความพึงพอใจของผู้ใช้งานต่อระบบ (N = 30) . 109

ตารางที่ ก.1 รายการชิ้นส่วนอุปกรณ์อิเล็กทรอนิกส์และราคาต้นทุน (Bill of Materials) . 127

สารบัญรูป

รูปที่ 3.1 แผนภาพ Use Case Diagram และสถาปัตยกรรมระบบรวม . . . . . . . . 48

รูปที่ 3.2 โมเดล 3D CAD ตัวเรือนนาฬิกา Smartwatch (SmartWatchV13 Comparison) . 53

รูปที่ 3.3 ผังการทำงานของเฟิร์มแวร์ฮาร์ดแวร์บน ESP32-C3 (Hardware Flowchart) . 55

รูปที่ 3.4 ผังการทำงานของระบบคลาวด์และเว็บแดชบอร์ด (Software Flowchart) . 73

รูปที่ 4.1 หน้าจอเข้าสู่ระบบผ่าน ThaID และ PIN . . . . . . . . . . . . . 79

รูปที่ 4.2 หน้าจอเข้าสู่ระบบด้วยรหัส PIN ส่วนบุคคล . . . . . . . . . . . 80

รูปที่ 4.3 หน้าจอลงทะเบียนผู้ป่วยใหม่ ส่วนข้อมูลส่วนบุคคล . . . . . . . . 81

รูปที่ 4.4 หน้าจอระบุอาการสำคัญ โรคประจำตัว และประวัติแพ้ยา . . . . . . . 82

รูปที่ 4.5 หน้าจอบันทึกยาประจำ ที่อยู่ ผู้ติดต่อฉุกเฉิน และการยินยอม PDPA . 83

รูปที่ 4.6 หน้าจอบัตรคิวรับบริการดิจิทัลบนสมาร์ตโฟนของผู้ป่วย . . . . . . 84

รูปที่ 4.7 หน้าจอแสดงผลคิวรอตรวจรวมทั้งแผนก (Live OPD Board) . . . . . . 85

รูปที่ 4.8 หน้าจอตรวจสอบคิวสดพร้อมป๊อปอัปบัตรคิวดิจิทัล . . . . . . . . . 86

รูปที่ 4.9 หน้าจอข้อมูลส่วนบุคคลและข้อมูลสุขภาพผู้ป่วย . . . . . . . . . 87

รูปที่ 4.10 หน้าจอรายการนัดหมายตรวจรักษา . . . . . . . . . . . . . . . . 87

รูปที่ 4.11 หน้าจอประวัติการรับบริการและการบันทึกค่าสัญญาณชีพ . . . . . . 88

รูปที่ 4.12 หน้าจอรายละเอียดข้อมูลผู้ป่วยและสรุปประวัติสุขภาพ . . . . . . 88

รูปที่ 4.13 หน้าต่างยืนยันการยกเลิกคิวรับบริการ (ขั้นตอนที่ 1) . . . . . 89

รูปที่ 4.14 หน้าต่างยืนยันการยกเลิกคิวรับบริการ (ขั้นตอนที่ 2) . . . . . 89

รูปที่ 4.15 หน้าจอแสดงสถานะเมื่อไม่มีคิวรับบริการในขณะนั้น . . . . . . . 90

รูปที่ 4.16 หน้าต่างแจ้งเตือนเมื่อผู้ป่วยมีคิวที่กำลังรอตรวจอยู่แล้ว . . 90

รูปที่ 4.17 หน้าต่างยืนยันการออกจากระบบ . . . . . . . . . . . . . . . . . 91

รูปที่ 4.18 หน้าจอการตั้งค่าระบบและความปลอดภัย . . . . . . . . . . . . . 91

รูปที่ 4.19 หน้าจอกรอกรหัส PIN 6 หลักสำหรับความปลอดภัย . . . . . . . . . 91

รูปที่ 4.20 หน้าจอยืนยันรหัส PIN 6 หลัก . . . . . . . . . . . . . . . . . 92

รูปที่ 4.21 หน้าจอแจ้งเตือนตั้งรหัส PIN สำเร็จ . . . . . . . . . . . . . 92

รูปที่ 4.22 หน้าจอปลดล็อกแอปพลิเคชันด้วย PIN . . . . . . . . . . . . . . 92

รูปที่ 4.23 หน้าจอแจ้งเตือนเมื่อกรอกรหัส PIN ไม่ถูกต้อง . . . . . . . . . 93

รูปที่ 4.24 หน้าจอตั้งค่าขนาดตัวอักษร (Accessibility) สำหรับผู้สูงอายุ . 93

รูปที่ 4.25 หน้าจอนโยบายความเป็นส่วนตัวและคุ้มครองข้อมูลสุขภาพ (PDPA Policy) . 93

รูปที่ 4.26 หน้าจอ Landing Page ยินดีต้อนรับผู้รับบริการ . . . . . . . . 94

รูปที่ ก.1 ผังวงจรอิเล็กทรอนิกส์และวงจรชาร์จแบตเตอรี่ Smartwatch (หน้าที่ 1) . 125

รูปที่ ก.2 ผังวงจรการเชื่อมต่อเซนเซอร์ MAX32664 และ MPU-6050 (หน้าที่ 2) . 126

คำอธิบายสัญลักษณ์และคำย่อ

OPD Outpatient Department (แผนกผู้ป่วยนอก)

ESI Emergency Severity Index (เกณฑ์การคัดแยกความรุนแรงผู้ป่วยฉุกเฉิน 5 ระดับ)

KTAS Korean Triage and Acuity Scale (ระบบคัดแยกผู้ป่วยและระดับความเฉียบพลัน)

PPG Photoplethysmography (การตรวจวัดปริมาตรหลอดเลือดด้วยแสง)

HR Heart Rate (อัตราการเต้นของหัวใจ, bpm)

SpO2 Peripheral Capillary Oxygen Saturation (ความอิ่มตัวของออกซิเจนในเลือดแดงส่วนปลาย, %)

BP Blood Pressure (ความดันโลหิต, SBP/DBP mmHg)

RR Respiratory Rate (อัตราการหายใจ, ครั้งต่อนาที)

BT Body Temperature (อุณหภูมิร่างกาย, °C)

SI Shock Index (ดัชนีช็อก = (HR)/(SBP) )

NEWS National Early Warning Score (เกณฑ์เตือนภัยสภาวะวิกฤตทางคลินิก)

IMU Inertial Measurement Unit (เซนเซอร์วัดความเฉื่อยและความเร่ง 6 แกน)

SVM Signal Vector Magnitude (เวกเตอร์ขนาดความเร่งรวม = √(a_x^2 +a_y^2 +a_z^2) )

SQI Signal Quality Index (ดัชนีชี้วัดคุณภาพและความน่าเชื่อถือของสัญญาณ)

NLP Natural Language Processing (การประมวลผลภาษาธรรมชาติ)

TF-IDF Term Frequency-Inverse Document Frequency (การถ่วงน้ำหนักความถี่คำในเอกสาร)

FSM Finite State Machine (แบบจำลองเครื่องสถานะจำกัด)

IoMT Internet of Medical Things (อินเทอร์เน็ตของสรรพสิ่งทางการแพทย์)

PDPA Personal Data Protection Act (พระราชบัญญัติคุ้มครองข้อมูลส่วนบุคคล พ.ศ. 2562)

ThaID ระบบพิสูจน์และยืนยันตัวตนทางดิจิทัลของกรมการปกครอง กระทรวงมหาดไทย

LUT Look-Up Table (ตารางค้นหาค่าเชิงเส้นสำหรับแปลงระดับแรงดันแบตเตอรี่)

SPA Single-Page Application (สถาปัตยกรรมเว็บแอปพลิเคชันหน้าเดียว)

บทที่ 1
บทนำ

1.1 ความเป็นมาและความสำคัญของปัญหา

ระบบการให้บริการสาธารณสุขของประเทศไทยในปัจจุบัน โดยเฉพาะอย่างยิ่งในแผนกผู้ป่วยนอก (Outpatient Department: OPD) ของโรงพยาบาลรัฐระดับตติยภูมิและโรงพยาบาลศูนย์ทั่วประเทศ กำลังเผชิญกับสภาวะความแออัดของผู้มารับบริการเป็นจำนวนมหาศาล โดยมีจำนวนผู้ป่วยนอกเฉลี่ยตั้งแต่ 1,500 ถึงมากกว่า 3,000 คนต่อวัน ส่งผลให้ระยะเวลาการรอคอยเพื่อเข้ารับการตรวจรักษาจากแพทย์หรือรับบริการทางการแพทย์มีระยะเวลายาวนานเฉลี่ย 2 ถึง 4 ชั่วโมง ในกระบวนการทำงานแบบดั้งเดิม ผู้ป่วยที่เดินทางมาถึงโรงพยาบาลจะได้รับการตรวจคัดกรองเบื้องต้น (Triage) ณ จุดคัดกรองหลัก เพื่อทำการวัดสัญญาณชีพพื้นฐาน เช่น ความดันโลหิต อัตราการเต้นของหัวใจ อุณหภูมิร่างกาย และค่าความอิ่มตัวของออกซิเจนในเลือด เพียงครั้งเดียวในตอนเริ่มต้น จากนั้นผู้ป่วยจะได้รับบัตรคิวและถูกส่งต่อไปยังพื้นที่พักคอยหน้าห้องตรวจของแต่ละแผนกเฉพาะทาง

ข้อจำกัดเชิงโครงสร้างที่สำคัญยิ่งของกระบวนการนี้คือ "ช่องว่างความเสี่ยงระหว่างการรอคอย" (Waiting Gap) เนื่องจากสัญญาณชีพของผู้ป่วยเป็นข้อมูลทางสรีรวิทยาที่มีความผันผวนและเปลี่ยนแปลงได้ตลอดเวลาตามพยาธิสภาพของโรค โดยเฉพาะในกลุ่มผู้ป่วยสูงอายุ ผู้ป่วยที่มีโรคประจำตัวเรื้อรัง (Non-Communicable Diseases: NCDs) เช่น โรคหัวใจและหลอดเลือด โรคเบาหวาน โรคความดันโลหิตสูง หรือผู้ป่วยที่มีภาวะติดเชื้อเฉียบพลัน ในระหว่างการนั่งรอตรวจเป็นเวลานานหลายชั่วโมง ผู้ป่วยอาจเกิดภาวะทรุดลงทางคลินิกอย่างเฉียบพลัน (Clinical Deterioration) เช่น ภาวะช็อกจากการไหลเวียนโลหิตล้มเหลว (Occult Shock ซึ่งมีค่า Shock Index > 0.9), ภาวะกล้ามเนื้อหัวใจขาดเลือดเฉียบพลัน (Acute Coronary Syndrome), ภาวะออกซิเจนในเลือดต่ำกะทันหัน (Hypoxemia), หรือการเกิดอุบัติเหตุพลัดตกหกล้มเนื่องจากอาการหน้ามืดหรือวิงเวียนศีรษะ ซึ่งในพื้นที่รอคอยที่มีความแออัด พยาบาลไม่สามารถตรวจตราผู้ป่วยทุกคนได้อย่างทั่วถึง ทำให้การตรวจพบความผิดปกติเกิดความล่าช้า จนอาจนำไปสู่ภาวะหัวใจหยุดเต้นกะทันหันหรือการเสียชีวิตที่สามารถป้องกันได้

นอกจากนี้ ระบบการจัดการคิวในโรงพยาบาลส่วนใหญ่ยังคงเป็นระบบคิวแบบคงที่ (Static First-Come, First-Served Queue) ที่จัดลำดับตามเวลาที่ผู้ป่วยมาถึงเป็นหลัก โดยไม่สามารถปรับเปลี่ยนลำดับความเร่งด่วนแบบไดนามิก (Dynamic Queue Prioritization) ตามสภาวะวิกฤตทางสรีรวิทยาที่เกิดขึ้นจริงในขณะนั้นได้ ขณะเดียวกันการสื่อสารสถานะคิวไปยังผู้ป่วยยังพึ่งพาป้ายประกาศหรือเสียงเรียกคิวแบบรวมศูนย์ ทำให้ผู้ป่วยไม่สามารถผละออกจากบริเวณหน้าห้องตรวจได้ ก่อให้เกิดความวิตกกังวลและความแออัดสะสม

ด้วยความก้าวหน้าของเทคโนโลยีอินเทอร์เน็ตของสรรพสิ่งทางการแพทย์ (Internet of Medical Things: IoMT), ระบบสมองกลฝังตัวพลังงานต่ำ, อัลกอริทึมการประมวลผลสัญญาณชีวภาพ (Biomedical Signal Processing), ปัญญาประดิษฐ์ช่วยคัดแยกความรุนแรง (AI-assisted Triage) ภายใต้แนวคิด Human-in-the-loop, และเทคโนโลยีเว็บแอปพลิเคชันสมัยใหม่ (Next.js App Router) จึงเป็นโอกาสสำคัญในการพัฒนาระบบ "อุปกรณ์สวมใส่ติดตามสุขภาพและเว็บแอปเช็คคิวผู้ป่วยนอก" เพื่อปิดช่องว่างความเสี่ยงในการรอคอย ติดตามสัญญาณชีพผู้ป่วยอย่างต่อเนื่องแบบเรียลไทม์ และสนับสนุนการตัดสินใจของพยาบาลในการบริหารจัดการคิวได้อย่างมีประสิทธิภาพสูงสุด

1.2 วัตถุประสงค์ของโครงงาน

1. เพื่อออกแบบและสร้างอุปกรณ์สวมใส่ต้นแบบ (Smart Watch Prototype) โดยใช้ไมโครคอนโทรลเลอร์ Seeed Studio XIAO ESP32-C3 ร่วมกับเซนเซอร์ MAX32664 และ MPU-6050 สำหรับตรวจวัดสัญญาณชีพ (Heart Rate, SpO2, Skin Temp, Estimated BP Trend) และตรวจจับการหกล้มแบบหลายขั้นตอนได้แบบเรียลไทม์

2. เพื่อพัฒนาระบบประมวลผลและกรองสัญญาณบนอุปกรณ์ (Edge Signal Filtering) ประกอบด้วยอัลกอริทึม Signal Quality Index (SQI), Skin-Contact Detection และ Finite State Machine สำหรับการตรวจจับการหกล้มเพื่อลดอัตราการแจ้งเตือนผิดพลาด (False Alarms)

3. เพื่อพัฒนาระบบปัญญาประดิษฐ์สนับสนุนการคัดแยกความรุนแรงของผู้ป่วย (AI-assisted Triage Decision Support) 5 ระดับ (RED, PINK, YELLOW, GREEN, WHITE) ผสานการประมวลผลข้อความ Chief Complaint ด้วย NLP และกฎทางคลินิก พร้อมแจกแจงเหตุผล (Explainable AI Reasons) ภายใต้แนวคิด Human-in-the-loop

4. เพื่อพัฒนาระบบเว็บแอปพลิเคชัน Next.js สำหรับพยาบาลในการติดตามสัญญาณชีพแบบรวมศูนย์ (Centralized Nurse Dashboard), การตรวจสอบและยืนยันผลความรุนแรง (Nurse Confirmation), และการจัดการคิวแบบพลวัต (Dynamic Queue Prioritization)

5. เพื่อพัฒนาระบบบัตรคิวดิจิทัลและการแจ้งเตือนบนสมาร์ตโฟนสำหรับผู้รับบริการ (Patient Mobile Web Queue Card) ผ่าน HTML5 Canvas API (queue-card-canvas.ts) และการเชื่อมต่อระบบยืนยันตัวตนดิจิทัล (ThaID และ PIN)

6. เพื่อทดสอบและประเมินประสิทธิภาพการทำงานของระบบแบบบูรณาการ ทั้งความแม่นยำของเซนเซอร์, ความไวและความจำเพาะของการตรวจจับการหกล้ม, ประสิทธิภาพโมเดล AI Triage, ความหน่วงเครือข่าย และความพึงพอใจของผู้ใช้งาน

1.3 สมมติฐานและแนวคิดการแก้ปัญหา

1. สมมติฐานด้านการประมวลผลสัญญาณ (Edge Processing & Motion Rejection): การใช้อัลกอริทึม SQI และการตรวจสอบความเข้มแสงอินฟราเรดสะท้อน (Skin-Contact IR Threshold) ร่วมกับข้อมูลความเร่งจาก MPU-6050 จะสามารถคัดกรองสัญญาณรบกวนจากการเคลื่อนไหว (Motion Artifacts) ได้ ทำให้ค่าความคลาดเคลื่อนในการวัดสัญญาณชีพ (HR และ SpO2) ไม่เกิน ±5% เมื่อเทียบกับเครื่องมือแพทย์มาตรฐาน

2. สมมติฐานด้านการตรวจจับการหกล้ม (Multi-Stage Fall Detection): การใช้อัลกอริทึม Finite State Machine ที่ตรวจสอบลำดับเหตุการณ์ Free-Fall (SVM < 0.5g) ตามด้วย Impact (SVM > 2.5g) และ Inactivity จะมีความไว (Sensitivity) ไม่น้อยกว่าร้อยละ 90 และลดการเตือนผิดพลาด (False Positives) จากกิจกรรมประจำวันให้เหลือ 0%

3. สมมติฐานด้าน AI-assisted Triage และ Human-in-the-loop: การผสานโมเดล Machine Learning ร่วมกับ Rule-based Logic จาก Vital Signs และ Chief Complaint จะให้ค่า Within-one-level Accuracy สูงกว่าร้อยละ 95 และการให้ AI เสนอแนะพร้อมเหตุผลประกอบ (AI Reasons) จะช่วยสนับสนุนให้พยาบาลยืนยันผล (Nurse Confirmation) ได้อย่างรวดเร็วและแม่นยำ

4. สมมติฐานด้านระบบจัดการคิวและการรอคอย: การจัดลำดับคิวแบบพลวัตตามดัชนีช็อก (Shock Index) และระดับความรุนแรงที่พยาบาลยืนยัน ร่วมกับการแจ้งเตือนคิวผ่านสมาร์ตโฟน จะช่วยลดความวิตกกังวลและเพิ่มระดับความพึงพอใจของผู้ใช้งานเฉลี่ยไม่น้อยกว่า 4.00 จาก 5.00 คะแนน

1.4 ขอบเขตของโครงงาน

1.4.1 ขอบเขตด้านฮาร์ดแวร์และอุปกรณ์สวมใส่ (Hardware Scope)

1) หน่วยประมวลผลหลัก: ใช้ไมโครคอนโทรลเลอร์ Seeed Studio XIAO ESP32-C3 สถาปัตยกรรม RISC-V 32 บิต ความถี่ 160 MHz รองรับ Wi-Fi 2.4 GHz และ BLE 5.0

2) โมดูลเซนเซอร์สัญญาณชีพ: ใช้ Maxim MAX32664 Biometric Sensor Hub ร่วมกับเซนเซอร์โฟโตพลีทิสโมกราฟี MAX30102 สำหรับตรวจวัดสัญญาณ PPG (Red 660 nm, IR 880 nm) ผ่านบัส I2C

3) เซนเซอร์วัดความเฉื่อย: ใช้ MPU-6050 6-DOF IMU (Accelerometer ±8g, Gyroscope ±1000°/s) ผ่านบัส I2C สำหรับการตรวจจับการหกล้มและการเคลื่อนไหว

4) จอแสดงผล: ใช้จอทรงกลม TFT LCD ขนาด 1.28 นิ้ว (ไดรเวอร์ GC9A01, ความละเอียด 240x240 พิกเซล) ผ่านบัส SPI

5) ระบบพลังงาน: แบตเตอรี่ Lithium-Polymer 3.7V 500 mAh พร้อมวงจรชาร์จ TP4056, วงจรป้องกัน DW01A, LDO AP2112K (3.3V 600mA) และวงจรแบ่งแรงดัน 100kΩ/100kΩ สำหรับตรวจวัดระดับแบตเตอรี่ผ่าน ADC

6) ตัวเรือนนาฬิกา: ออกแบบด้วยโปรแกรม FreeCAD และขึ้นรูปด้วยเทคโนโลยีการพิมพ์ 3 มิติ (FDM) ด้วยวัสดุ PETG/PLA ขนาดกะทัดรัด (SmartWatchV13)

1.4.2 ขอบเขตด้านซอฟต์แวร์และระบบคลาวด์ (Software Scope)

1) เว็บแอปพลิเคชันส่วนหน้า: พัฒนาด้วย Next.js 16.3.0 (App Router), React 19.2.8, TypeScript 5.9.3, และ Tailwind CSS รองรับการแสดงผล Responsive แบบ Single-Page Application (SPA)

2) โครงสร้างโฟลเดอร์ซอฟต์แวร์: จัดระเบียบแบบ Feature-Driven Architecture แบ่งออกเป็น `src/features/account`, `src/features/auth`, `src/features/queue`, `src/features/registration`, `src/features/settings`, `src/shared/api`, `src/shared/auth`, `src/shared/config`, และ `src/shared/data`

3) การกำหนดค่าขณะรันไทม์ (Runtime Configuration): อ่านค่าสภาพแวดล้อมจาก `public/runtime-config.js` ผ่าน `window.PATIENT_APP_ENV` เพื่อกำหนด `PATIENT_API_BASE_URL` และ `PATIENT_STATUS_REFRESH_MS` ได้โดยไม่ต้องบิลด์แอปใหม่

4) ระบบฐานข้อมูลและคลาวด์: ใช้ Firebase Cloud Firestore และ Realtime Database สำหรับจัดเก็บข้อมูล 8 เอนทิตีหลัก (`Patient`, `Device`, `Vital`, `Telemetry`, `Triage`, `Alert`, `Queue`, `Nurse`)

5) ระบบความปลอดภัยและการยืนยันตัวตน: รองรับการเข้าสู่ระบบด้วย ThaID OpenID Connect, รหัสผ่านส่วนบุคคล 6 หลัก (PIN Hashing), นโยบาย PDPA Consent, และระบบรักษาความปลอดภัย API ด้วย Token และ Device Pairing Verification (HTTP 409 ปฏิเสธการส่งข้อมูลจากอุปกรณ์ที่ยังไม่จับคู่)

6) ระบบบัตรคิวดิจิทัล: สร้างรูปภาพบัตรคิวแบบไดนามิกผ่าน HTML5 Canvas API (`queue-card-canvas.ts`) และระบบตรวจสอบคิวผ่าน Polling Mechanism (`useQueuePolling.ts`)

7) ชุดการทดสอบอัตโนมัติ (Automated Testing Suite): พัฒนาชุดทดสอบ Unit/Component Tests ด้วย Vitest 4.1.10 และ React Testing Library 16.3.2

1.4.3 ขอบเขตด้านปัญญาประดิษฐ์และการคัดแยกผู้ป่วย (AI Triage Scope)

1) การจำแนกระดับความรุนแรง: รองรับ 5 ระดับ ได้แก่ RED (วิกฤตฉุกเฉิน), PINK (ฉุกเฉินเร่งด่วน), YELLOW (เร่งด่วนปานกลาง), GREEN (ไม่เร่งด่วน), และ WHITE (ทั่วไป)

2) การวิเคราะห์อาการสำคัญ (Chief Complaint): ประมวลผลข้อความภาษาไทยด้วยเทคนิค NLP (Tokenization, TF-IDF Unigram/Bigram) ร่วมกับโมเดลการเรียนรู้ของเครื่อง

3) กฎคัดกรองฉุกเฉิน (Rule-based Overrides): กำหนดกฎทางการแพทย์ เช่น SpO2 < 90%, Shock Index > 0.9, หรือมีเหตุการณ์ Fall Detection ให้ปรับเป็นระดับวิกฤตทันที

4) สถาปัตยกรรม Human-in-the-loop: ระบบจะแสดงผลเป็น "AI Suggested Severity" พร้อมแจกแจงเหตุผล (Explainable Reasons) โดยให้พยาบาลทำการตรวจสอบและกดยืนยันหรือปรับแก้เป็น "Nurse Confirmed Severity" ซึ่งเป็นค่าจริงที่ใช้ในการจัดคิว

1.5 ข้อตกลงเบื้องต้น

1. ผู้ป่วยที่เข้ารับการทดสอบจะต้องสวมใส่อุปกรณ์สวมใส่ไว้ที่บริเวณข้อมือในลักษณะที่กระชับแนบสนิทกับผิวหนังอย่างเหมาะสม และอยู่ในสภาวะพักผ่อนหรือไม่มีการขยับแขนอย่างรุนแรงในขณะที่เซนเซอร์ทำการวัดค่าสัญญาณชีพ

2. พื้นที่ทดสอบและพื้นที่รอคอยภายในสถานพยาบาลมีสัญญาณเครือข่ายอินเทอร์เน็ตไร้สาย (Wi-Fi 2.4 GHz) ครอบคลุมอย่างสม่ำเสมอและมีความเสถียรเพียงพอสำหรับการรับส่งข้อมูล

3. ผู้ป่วยหรือญาติผู้ดูแลมีอุปกรณ์สมาร์ตโฟนที่สามารถเชื่อมต่อเครือข่ายอินเทอร์เน็ตและเปิดใช้งานโปรแกรมเว็บเบราว์เซอร์มาตรฐานที่รองรับเทคโนโลยีเว็บสมัยใหม่ได้

1.6 ข้อจำกัดของโครงงาน

1. อุปกรณ์สวมใส่ต้นแบบที่พัฒนาขึ้นได้รับการออกแบบเพื่อการวิจัยและติดตามสัญญาณชีพเบื้องต้นเท่านั้น ไม่สามารถนำไปใช้ทดแทนเครื่องมือแพทย์ระดับวินิจฉัยโรคขั้นสูง (Diagnostic Medical Devices) หรืออุปกรณ์ช่วยชีวิตในห้องไอซียูได้

2. ค่าความดันโลหิตที่ได้จากเซนเซอร์เชิงแสง (MAX32664) เป็นค่าประมาณการแนวโน้มการเปลี่ยนแปลง (Estimated Blood Pressure Trend) ซึ่งต้องอาศัยการเทียบมาตรฐาน (Calibration) กับเครื่องวัดความดันโลหิตแบบบีบแขนมาตรฐาน (Cuff-based Sphygmomanometer) ของผู้ป่วยแต่ละบุคคล

3. ระบบปัญญาประดิษฐ์ช่วยคัดกรอง (AI Triage) ทำหน้าที่เป็นระบบสนับสนุนการตัดสินใจ (Decision Support System) เพื่อเสนอแนะระดับความรุนแรงและเหตุผลประกอบเท่านั้น โดยคำตัดสินใจขั้นสุดท้ายต้องขึ้นอยู่กับดุลยพินิจของพยาบาลวิชาชีพเสมอ

4. ชุดข้อมูลสำหรับการฝึกฝนโมเดล AI ยังมีขอบเขตจำกัดเฉพาะกลุ่มอาการสำคัญที่พบบ่อยในแผนกผู้ป่วยนอก และยังไม่ได้ผ่านการทดสอบทางคลินิกจริงในโรงพยาบาลขนาดใหญ่ (Clinical Trial)

1.7 ประโยชน์ที่คาดว่าจะได้รับ

1.7.1 ประโยชน์ต่อผู้รับบริการ (ผู้ป่วยและญาติ): ช่วยเพิ่มความปลอดภัยระหว่างการรอคอย โดยได้รับการเฝ้าระวังสัญญาณชีพอย่างต่อเนื่อง ได้รับการช่วยเหลือทันท่วงทีหากเกิดภาวะวิกฤตหรือหกล้ม สามารถตรวจสอบลำดับคิวและประมาณเวลาตรวจผ่านสมาร์ตโฟนได้ ช่วยลดความวิตกกังวลและลดความแออัดในพื้นที่รอคอย

1.7.2 ประโยชน์ต่อบุคลากรทางการแพทย์ (พยาบาลและเจ้าหน้าที่): ช่วยลดภาระงานในการเดินตรวจวัดสัญญาณชีพซ้ำ มีหน้าจอกระดานรวมศูนย์ (Nurse Dashboard) แสดงสถานะสุขภาพของผู้ป่วยทุกคนแบบเรียลไทม์ ได้รับคำแนะนำระดับความรุนแรงจาก AI พร้อมเหตุผลประกอบเพื่อช่วยตัดสินใจ และสามารถจัดลำดับคิวผู้ป่วยที่มีภาวะวิกฤตให้ได้รับการตรวจก่อนได้อย่างเป็นระบบ

1.7.3 ประโยชน์ต่อสถานพยาบาลและการบริหารจัดการ: ช่วยลดความแออัดสะสม ยกระดับการให้บริการทางการแพทย์สู่มาตรฐานโรงพยาบาลอัจฉริยะ (Smart Hospital) และมีข้อมูลสถิติสัญญาณชีพย้อนหลังสำหรับประเมินคุณภาพการให้บริการ

1.7.4 ประโยชน์ทางวิชาการและวิศวกรรมศาสตร์: ได้องค์ความรู้และต้นแบบในการบูรณาการเทคโนโลยีระบบสมองกลฝังตัว, การประมวลผลสัญญาณชีวภาพบนขอบเครือข่าย (Edge Processing), ปัญญาประดิษฐ์ทางการแพทย์ภายใต้แนวคิด Human-in-the-loop, และการพัฒนาเว็บแอปพลิเคชันสารสนเทศสุขภาพ

1.8 แผนการดำเนินงานและระยะเวลา

การดำเนินงานโครงงานมีระยะเวลาตลอด 2 ภาคการศึกษา (ปีการศึกษา 2568) โดยมีแผนภูมิแกนต์และรายละเอียดการดำเนินงานดังแสดงในตารางที่ 1.1

ตารางที่ 1.1 แผนการดำเนินงานและแผนภูมิแกนต์ตลอด 2 ภาคการศึกษา

กิจกรรม / ขั้นตอนการดำเนินงาน | ก.ค. | ส.ค. | ก.ย. | ต.ค. | พ.ย. | ธ.ค. | ม.ค. | ก.พ. | มี.ค.
1. ศึกษาความเป็นมา ทฤษฎี และงานวิจัยที่เกี่ยวข้อง | ■ | ■
2. วิเคราะห์ความต้องการและออกแบบสถาปัตยกรรมระบบ | | ■ | ■
3. ออกแบบวงจรฮาร์ดแวร์และตัวเรือนนาฬิกา 3D CAD | | | ■ | ■
4. พัฒนาเฟิร์มแวร์ ESP32-C3 และตัวกรองสัญญาณ Edge | | | | ■ | ■
5. พัฒนาระบบ AI Triage (NLP/Rules) & Database | | | | | ■ | ■
6. พัฒนาเว็บแอปพลิเคชัน Next.js & Nurse Dashboard | | | | | | ■ | ■
7. รวมระบบ (System Integration) และทดสอบฟังก์ชัน | | | | | | | ■ | ■
8. ทดสอบความแม่นยำเซนเซอร์, Fall, AI, และ Latency | | | | | | | | ■ | ■
9. ประเมินความพึงพอใจและจัดทำเล่มรายงานปริญญานิพนธ์ | | | | | | | | | ■

1.9 ประมาณการงบประมาณและค่าใช้จ่าย

ค่าใช้จ่ายในการจัดหาอุปกรณ์ฮาร์ดแวร์ ชิ้นส่วนอิเล็กทรอนิกส์ และเครื่องมือในการพัฒนาโครงงาน แสดงรายละเอียดในตารางที่ 1.2

ตารางที่ 1.2 ประมาณการงบประมาณและค่าใช้จ่ายในการพัฒนาโครงงาน (BOM)

ลำดับ | รายการอุปกรณ์ / ชิ้นส่วน | จำนวน | ราคาต่อหน่วย (บาท) | ราคารวม (บาท)
1 | บอร์ดไมโครคอนโทรลเลอร์ Seeed Studio XIAO ESP32-C3 | 2 บอร์ด | 220.00 | 440.00
2 | โมดูลประมวลผลสัญญาณชีวภาพ MAX32664 + MAX30102 | 2 ชุด | 550.00 | 1,100.00
3 | โมดูลเซนเซอร์วัดความเฉื่อย 6 แกน MPU-6050 (GY-521) | 2 ชุด | 65.00 | 130.00
4 | หน้าจอแสดงผลทรงกลม Round TFT LCD 1.28" GC9A01 | 2 ชุด | 180.00 | 360.00
5 | แบตเตอรี่ Lithium-Polymer 3.7V 500 mAh พร้อมวงจรชาร์จ | 2 ชุด | 120.00 | 240.00
6 | วัสดุเส้นพลาสติก 3D Printing (PETG/PLA) สำหรับพิมพ์ตัวเรือน | 1 ม้วน | 450.00 | 450.00
7 | สายรัดข้อมือซิลิโคนมาตรฐานและอุปกรณ์ประกอบตัวเรือน | 2 ชุด | 90.00 | 180.00
8 | อุปกรณ์อิเล็กทรอนิกส์ย่อย (LDO, Resistors, Switch, สายไฟ) | 1 ชุด | 200.00 | 200.00
9 | ค่าบริการคลาวด์และเซิร์ฟเวอร์ทดสอบระบบ (Firebase/Hosting) | 1 ระบบ | 0.00 | 0.00 (Free Tier)
รวมงบประมาณทั้งสิ้น (บาท) | | | | 3,100.00

1.10 คำนิยามศัพท์เฉพาะ

• แผนกผู้ป่วยนอก (Outpatient Department: OPD): หน่วยบริการทางการแพทย์ของโรงพยาบาลที่ให้การตรวจวินิจฉัยและรักษาผู้ป่วยที่ไม่ได้นอนพักรักษาตัวค้างคืนในโรงพยาบาล

• การคัดกรองและประเมินระดับความรุนแรง (Triage): กระบวนการจำแนกและจัดลำดับความเร่งด่วนในการตรวจรักษาผู้ป่วยตามระดับความรุนแรงของอาการและสัญญาณชีพทางสรีรวิทยา

• ระบบคัดแยก 5 ระดับ (5-Level Triage): การจำแนกระดับความรุนแรงของผู้ป่วยออกเป็น 5 ระดับตามเกณฑ์ ESI/KTAS ได้แก่ RED (วิกฤต), PINK (ฉุกเฉิน), YELLOW (เร่งด่วน), GREEN (ไม่เร่งด่วน), และ WHITE (ทั่วไป)

• ปัญญาประดิษฐ์ช่วยคัดกรอง (AI-assisted Triage): ระบบประมวลผลสัญญาณชีพและข้อความอาการสำคัญด้วยแบบจำลอง Machine Learning และกฎทางคลินิก เพื่อสร้างข้อเสนอแนะระดับความรุนแรง (AI Suggested Severity) และแจกแจงเหตุผลประกอบ

• มนุษย์เป็นศูนย์กลางในการตัดสินใจ (Human-in-the-loop): แนวคิดทางวิศวกรรมซอฟต์แวร์การแพทย์ที่กำหนดให้ผลลัพธ์จาก AI เป็นเพียงคำแนะนำ โดยมีพยาบาลวิชาชีพเป็นผู้ตรวจสอบและยืนยันผลขั้นสุดท้าย (Nurse Confirmed Severity) ซึ่งเป็นค่าเดียวที่นำไปใช้จัดคิว

• ความแม่นยำแบบยอมรับความคลาดเคลื่อน 1 ระดับ (Within-one-level Accuracy): ดัชนีชี้วัดความแม่นยำของแบบจำลองคัดแยกผู้ป่วย โดยนับผลการทำนายที่ถูกต้องหรือคลาดเคลื่อนไม่เกิน ±1 ระดับจากระดับความรุนแรงจริง (เช่น AI ทำนาย YELLOW แต่ผลจริงคือ PINK หรือ GREEN)

• ความแม่นยำเชิงเส้นทางบริการ (Route Accuracy): ความแม่นยำในการจัดกลุ่มระดับความรุนแรงเข้าสู่เส้นทางบริการหลักของโรงพยาบาล (Fast Track: RED/PINK, Regular Clinic: YELLOW/GREEN/WHITE)

• สัญญาณโทรมาตรทางการแพทย์ (Telemetry Data): ข้อมูลการตรวจวัดสัญญาณชีพและสภาวะการเคลื่อนไหวที่ถูกส่งผ่านเครือข่ายไร้สายจากอุปกรณ์สวมใส่ขึ้นสู่ระบบคลาวด์เซิร์ฟเวอร์แบบเรียลไทม์

• โฟโตพลีทิสโมกราฟี (Photoplethysmography: PPG): เทคนิคเชิงแสงที่ใช้วัดการเปลี่ยนแปลงของปริมาตรเลือดในหลอดเลือดฝอยใต้ผิวหนังด้วยแสงสีแดงและอินฟราเรด เพื่อคำนวณอัตราการเต้นของหัวใจและความอิ่มตัวของออกซิเจน

• ดัชนีช็อก (Shock Index: SI): อัตราส่วนระหว่างอัตราการเต้นของหัวใจ (HR) ต่อค่าความดันโลหิตซิสโตลิก (SBP) โดยค่า SI > 0.9 บ่งชี้ภาวะเสี่ยงต่อการไหลเวียนโลหิตล้มเหลวเฉียบพลัน

• การตรวจจับการหกล้มแบบหลายขั้นตอน (Multi-Stage Fall Detection): อัลกอริทึม Finite State Machine ที่ตรวจจับลำดับเหตุการณ์ Free-Fall, Impact, และ Post-Impact Inactivity ต่อเนื่องกันเพื่อลด False Positives จากกิจกรรมประจำวัน

• การจับคู่อุปกรณ์อย่างปลอดภัย (Device Pairing): กระบวนการผูกรหัสประจำตัวอุปกรณ์สวมใส่ (Device ID) เข้ากับรหัสประจำตัวผู้ป่วย (Patient ID) และการตรวจรับรองสิทธิ์ผ่าน Token เพื่อป้องกันการส่งข้อมูลจากอุปกรณ์แปลกปลอม (HTTP 409 Conflict)

• หน่วยความจำสำรองแบบวงกลม (Offline Ring Buffer): โครงสร้างข้อมูลแบบ Circular Buffer บน ESP32 สำหรับบันทึกข้อมูลสัญญาณชีพชั่วคราวเมื่อการเชื่อมต่อ Wi-Fi ขาดหาย และส่งย้อนหลังขึ้นคลาวด์เมื่อสัญญาณกลับมา

• เว็บแอปพลิเคชันหน้าเดียว (Single-Page Application: SPA): รูปแบบสถาปัตยกรรมเว็บแอปพลิเคชันที่โหลดหน้าเว็บเพียงครั้งเดียวและสลับเปลี่ยนมุมมอง (Views) ภายในฝั่งเบราว์เซอร์ ช่วยให้การใช้งานผ่านการสแกน QR Code มีความราบรื่นโดยไม่ต้องรีเฟรชหน้าต่าง

บทที่ 2
ทฤษฎีและงานวิจัยที่เกี่ยวข้อง

ในบทนี้จะกล่าวถึงหลักการ ทฤษฎีพื้นฐานทางวิศวกรรมศาสตร์ เทคโนโลยีสารสนเทศสุขภาพ และผลงานวิจัยที่เกี่ยวข้อง ซึ่งเป็นรากฐานสำคัญในการออกแบบและพัฒนาระบบอุปกรณ์สวมใส่ติดตามสัญญาณชีพและเว็บแอปพลิเคชันคัดแยกผู้ป่วยอัจฉริยะสำหรับการจัดการคิวผู้ป่วยนอก โดยครอบคลุมหัวข้อสำคัญดังต่อไปนี้

2.1 ระบบคัดแยกผู้ป่วย 5 ระดับ (5-Level Triage Systems)

การคัดแยกผู้ป่วยในแผนกผู้ป่วยนอกและแผนกฉุกเฉินสากลนิยมใช้ระบบคัดกรอง 5 ระดับ เช่น Emergency Severity Index (ESI) ของสหรัฐอเมริกา และ Korean Triage and Acuity Scale (KTAS) ของประเทศเกาหลีใต้ ซึ่งได้รับการพิสูจน์แล้วว่ามีประสิทธิภาพและความปลอดภัยสูงกว่าระบบคัดกรองแบบ 3 ระดับดั้งเดิม ในโครงงานนี้ได้นำหลักการดังกล่าวมาปรับประยุกต์ให้สอดคล้องกับบริบทของแผนกผู้ป่วยนอก (OPD) โดยแบ่งระดับความรุนแรงออกเป็น 5 ระดับดังนี้:

1. ระดับที่ 1 (RED - Resuscitation/Critical): ผู้ป่วยภาวะวิกฤตคุกคามต่อชีวิต เช่น ภาวะหัวใจหยุดเต้น, ภาวะช็อกรุนแรง (Shock Index > 0.9), ค่า SpO2 < 90%, หรือเกิดการหกล้มและหมดสติ ต้องได้รับการกู้ชีพและเข้าพบแพทย์ทันทีโดยไม่ต้องรอคิว

2. ระดับที่ 2 (PINK - Emergent): ผู้ป่วยที่มีความรุนแรงสูง มีสัญญาณชีพผิดปกติเด่นชัด หรือมีอาการสำคัญที่มีความเสี่ยงสูง เช่น เจ็บแน่นหน้าอกรุนแรง, หายใจลำบาก, ค่า SpO2 90-92%, หรือ HR > 130 bpm ควรได้รับการประเมินและตรวจรักษาภายใน 10-15 นาที

3. ระดับที่ 3 (YELLOW - Urgent): ผู้ป่วยที่มีความผิดปกติปานกลาง สัญญาณชีพคงที่แต่อาจทรุดลงได้หากรอนานเกินไป เช่น ไข้สูงร่วมกับชีพจรเร็ว, ปวดท้องรุนแรง, หรือมีโรคประจำตัวร่วม ควรได้รับการตรวจภายใน 30-45 นาที

4. ระดับที่ 4 (GREEN - Less Urgent): ผู้ป่วยที่มีอาการไม่รุนแรง สัญญาณชีพปกติ เช่น อาการหวัด, ผื่นแพ้, ปวดศีรษะเล็กน้อย สามารถรอตรวจตามลำดับคิวปกติได้ (ภายใน 60-90 นาที)

5. ระดับที่ 5 (WHITE - Non-Urgent): ผู้ป่วยทั่วไปที่มารับบริการตามนัด, ขอใบรับรองแพทย์, หรือรับยาต่อเนื่อง สัญญาณชีพปกติทุกรายการ สามารถรอรับบริการได้โดยไม่มีความเสี่ยงทางการแพทย์

ตารางที่ 2.1 เกณฑ์ค่ามาตรฐานสัญญาณชีพและระดับภาวะวิกฤตทางการแพทย์ (NEWS/MEWS)

พารามิเตอร์สัญญาณชีพ | ระดับปกติ (Normal) | ระดับเฝ้าระวัง (Warning) | ระดับวิกฤตฉุกเฉิน (Critical / Danger)
อัตราการเต้นของหัวใจ (Heart Rate: HR) | 60 – 100 bpm | 50 – 59 หรือ 101 – 120 bpm | < 50 หรือ > 120 bpm
ความอิ่มตัวของออกซิเจน (SpO2) | 95 – 100 % | 92 – 94 % | < 92 % (วิกฤต < 90%)
ความดันโลหิตซิสโตลิก (SBP) | 100 – 139 mmHg | 90 – 99 หรือ 140 – 159 mmHg | < 90 หรือ >= 160 mmHg
ความดันโลหิตไดแอสโตลิก (DBP) | 60 – 89 mmHg | 85 – 89 mmHg | < 60 หรือ >= 100 mmHg
อุณหภูมิร่างกาย (Body Temp: BT) | 36.5 – 37.4 °C | 37.5 – 38.4 °C (ไข้ต่ำ) | >= 38.5 °C หรือ < 35.5 °C
ดัชนีช็อก (Shock Index: SI = HR/SBP) | 0.5 – 0.7 | 0.7 – 0.9 (ภาวะเสี่ยง) | > 0.9 (ภาวะช็อกเฉียบพลัน)

2.2 ทฤษฎีสัญญาณชีพและการประเมินทางสรีรวิทยา

สัญญาณชีพเป็นตัวบ่งชี้สรีรวิทยาพื้นฐานที่สะท้อนถึงการทำงานของระบบสำคัญในร่างกาย การตรวจวัดสัญญาณชีพอย่างต่อเนื่องช่วยให้สามารถตรวจพบสัญญาณเตือนของการทรุดลงของอาการได้ล่วงหน้า โดยเฉพาะการประเมินดัชนีช็อก (Shock Index: SI) ซึ่งเสนอโดย Rady et al. (1994) ดังแสดงในสมการ (2.1)

SI=(HR)/(SBP) (2.1)

เมื่อ SI แทน ดัชนีช็อก (ไร้หน่วย), HR แทน อัตราการเต้นของหัวใจ (ครั้งต่อนาที, bpm), และ SBP แทน ค่าความดันโลหิตซิสโตลิก (มิลลิเมตรปรอท, mmHg) ในภาวะปกติค่า SI จะอยู่ระหว่าง 0.5 ถึง 0.7 หากค่า SI สูงกว่า 0.9 จะมีความไวสูงมากในการบ่งชี้ภาวะ Left Ventricular Failure และ Occult Shock แม้ว่าค่าความดันโลหิตตัวบนจะยังไม่ลดลงต่ำกว่า 90 mmHg ก็ตาม

2.3 เทคโนโลยีอุปกรณ์สวมใส่และเซนเซอร์โฟโตพลีทิสโมกราฟี (PPG)

เทคนิคโฟโตพลีทิสโมกราฟี (Photoplethysmography: PPG) เป็นการตรวจวัดทางทัศนศาสตร์โดยใช้แสงความยาวคลื่นเฉพาะฉายผ่านผิวหนัง เพื่อตรวจวัดการเปลี่ยนแปลงของปริมาตรเลือดในหลอดเลือดฝอยในแต่ละรอบการบีบตัวของหัวใจ การคำนวณค่า SpO2 อาศัยคุณสมบัติทางสเปกโทรสโกปีของออกซีฮีโมโกลบิน (HbO2) ซึ่งดูดกลืนแสงอินฟราเรด (880-940 nm) ได้ดี และดีออกซีฮีโมโกลบิน (Hb) ซึ่งดูดกลืนแสงสีแดง (660 nm) ได้ดี โดยระบบจะคำนวณอัตราส่วนการดูดกลืนแสง (Ratio of Ratios: R) จากสัญญาณกระแสสลับ (AC) และกระแสตรง (DC) ดังแสดงในสมการ (2.2)

R=((AC_(red))/(DC_(red)))/((AC_(ir))/(DC_(ir))) (2.2)

จากนั้นจะนำค่า R ไปแปลงเป็นค่าความอิ่มตัวของออกซิเจนในเลือด (SpO2) ผ่านสมการเทียบมาตรฐานเชิงประจักษ์ ดังแสดงในสมการ (2.3)

SpO_2 =110−25×R (2.3)

ตารางที่ 2.2 การเปรียบเทียบคุณสมบัติของเซนเซอร์ PPG และชิปประมวลผล

คุณสมบัติ / พารามิเตอร์ | MAX30100 | MAX30102 | MAX32664 Biometric Hub (โครงงานนี้)
ไฟ LED กำเนิดแสง | Red (660nm) + IR (880nm) | Red (660nm) + IR (880nm) | Red (660nm) + IR (880nm) ผ่าน MAX30102
ADC Resolution | 14-bit | 18-bit | 18-bit ภายในตัวเซนเซอร์
On-chip Algorithm DSP | ไม่มี (MCU ต้องคำนวณดิบเอง) | ไม่มี (MCU ต้องคำนวณดิบเอง) | มี Micro-DSP บรรจุเฟิร์มแวร์คำนวณ HR/SpO2/BP
การขจัด Motion Artifact | จำกัดมาก (เกิด Noise สูง) | จำกัด (ต้องพึ่งพาซอฟต์แวร์ MCU) | มีระบบ Digital Filtering ในตัวฮาร์ดแวร์
การประเมินความดัน (BP Trend) | ไม่รองรับ | ไม่รองรับ | รองรับ Pulse Wave Morphology Analysis
ภาระการประมวลผลบน MCU | สูงมาก (MCU รันตลอดเวลา) | สูง (กินพลังงาน CPU) | ต่ำมาก (MCU เพียงแค่อ่านค่าผลลัพธ์ผ่าน I2C)

2.4 ทฤษฎีการตรวจจับการเคลื่อนไหวและการหกล้ม (Fall Detection)

การตรวจจับการหกล้มด้วยเซนเซอร์วัดความเฉื่อย 6 แกน (MPU-6050) อาศัยการคำนวณค่าเวกเตอร์ความเร่งรวม (Signal Vector Magnitude: SVM) จากแกน X, Y, Z ดังแสดงในสมการ (2.4)

SVM=√(a_x^2 +a_y^2 +a_z^2) (2.4)

โครงงานนี้ไม่ใช้การตัดสินใจแบบค่าขีดเริ่มเปลี่ยนเดี่ยว (Single-threshold) เนื่องจากจะทำให้เกิดการเตือนผิดพลาด (False Positive) สูงมากจากการโยน วิ่ง หรือการทุบโต๊ะ แต่ใช้อัลกอริทึม Finite State Machine ที่ตรวจสอบลำดับเหตุการณ์จริง 3 ระยะต่อเนื่องกัน ได้แก่: 1) ระยะตกอิสระ (Free Fall Phase) ที่ค่า SVM ลดลงต่ำกว่า 0.5g 2) ระยะกระแทกพื้น (Impact Phase) ที่ค่า SVM พุ่งสูงเกิน 2.5g และ 3) ระยะนอนนิ่งไร้การเคลื่อนไหว (Post-fall Inactivity Phase) ต่อเนื่องอย่างน้อย 5 วินาที

2.5 การประมวลผลภาษาธรรมชาติ (NLP) สำหรับวิเคราะห์อาการสำคัญ

ข้อมูลอาการสำคัญ (Chief Complaint) ที่ผู้ป่วยระบุในขั้นตอนการลงทะเบียน เช่น "เจ็บแน่นหน้าอก หายใจไม่ออก ร้าวไปที่แขนซ้าย" เป็นข้อมูลข้อความที่สามารถนำมาสกัดคุณลักษณะด้วยเทคนิค NLP โดยเริ่มต้นจากการตัดคำภาษาไทย (Tokenization), การตัดคำหยุด (Stop words removal), และการแปลงข้อความเป็นเวกเตอร์ตัวเลขด้วย Term Frequency-Inverse Document Frequency (TF-IDF) แบบ Unigram และ Bigram เพื่อส่งต่อไปยังแบบจำลอง Machine Learning ในการจำแนกกลุ่มอาการ

2.6 แบบจำลองการเรียนรู้ของเครื่องและการประเมินผล

ในการจำแนกระดับความรุนแรงของอาการผู้ป่วย โครงงานได้ศึกษาแบบจำลองการเรียนรู้ของเครื่อง เช่น Logistic Regression, Support Vector Machine (SVM), และ Random Forest Classifier ซึ่งทำการเรียนรู้จากเวกเตอร์คุณลักษณะที่ประกอบด้วยค่าสัญญาณชีพ (HR, SpO2, SBP, DBP, BT, RR, Pain Score) ร่วมกับเวกเตอร์ข้อความอาการสำคัญ การประเมินประสิทธิภาพของโมเดลใช้ตัวชี้วัด Accuracy, Precision, Recall, F1-Score, Confusion Matrix 5x5, และตัวชี้วัดเฉพาะทางการแพทย์ ได้แก่ Within-one-level Accuracy และ Route Accuracy เพื่อประเมินความปลอดภัยในการคัดแยกผู้ป่วย

2.7 สถาปัตยกรรมปัญญาประดิษฐ์สนับสนุนการตัดสินใจและ Human-in-the-loop

หลักการสำคัญของระบบปัญญาประดิษฐ์ทางการแพทย์คือ AI ไม่ใช่ผู้ตัดสินใจสูงสุดและไม่ใช่เครื่องมือวินิจฉัยโรค โครงงานนี้จึงออกแบบสถาปัตยกรรมแบบ Human-in-the-loop โดยแบ่งข้อมูลออกเป็น 2 ชั้นอย่างเด็ดขาด:

1. AI Suggested Severity: ระดับความรุนแรงที่ระบบ AI และ Rule Engine เสนอแนะ พร้อมทั้งแสดงรายการเหตุผลประกอบอย่างโปร่งใส (Explainable AI Reasons เช่น "SpO2 < 90% และพบคำสำคัญเจ็บแน่นหน้าอก") เพื่อลดสภาวะกล่องดำ (Black-Box Problem)

2. Nurse Confirmed Severity: ระดับความรุนแรงที่พยาบาลวิชาชีพเป็นผู้ตรวจสอบอาการจริงของผู้ป่วยและกดยืนยัน (Confirm) หรือปรับแก้ไข (Modify) โดยระบบจะใช้ Nurse Confirmed Severity นี้เพียงค่าเดียวในการจัดลำดับคิวและดำเนินการทางการแพทย์

2.8 สถาปัตยกรรมเว็บแอปพลิเคชันและการสื่อสารเครือข่าย

ระบบเว็บแอปพลิเคชันพัฒนาด้วย Next.js 16.3 (App Router) บนพื้นฐานของ React 19 และ TypeScript 5 ซึ่งรองรับการเรนเดอร์แบบ React Server Components (RSC) เพื่อความรวดเร็วในการโหลดข้อมูล และ Client Components สำหรับการโต้ตอบแบบเรียลไทม์ การสื่อสารระหว่างเว็บแอปพลิเคชันและอุปกรณ์สวมใส่ดำเนินการผ่าน RESTful API บนโปรโตคอล HTTPS ร่วมกับระบบ Interval Polling (`useQueuePolling.ts`) ทุกๆ 5-10 วินาที เพื่อดึงสถานะคิวล่าสุดอย่างมีประสิทธิภาพและลดภาระเซิร์ฟเวอร์ และใช้ HTML5 Canvas API ในการเรนเดอร์ภาพบัตรคิวดิจิทัลความละเอียดสูงแบบ Client-side (`queue-card-canvas.ts`)

2.9 ระบบความปลอดภัยข้อมูลสุขภาพและการยืนยันตัวตน

ข้อมูลสุขภาพและสัญญาณชีพจัดเป็นข้อมูลส่วนบุคคลที่มีความอ่อนไหวเป็นพิเศษตามพระราชบัญญัติคุ้มครองข้อมูลส่วนบุคคล พ.ศ. 2562 (PDPA) ระบบจึงมีหน้าต่างยินยอมข้อมูล (`PdpaConsentModal.tsx`) ในการลงทะเบียนครั้งแรก พร้อมระบบยืนยันตัวตนผ่าน ThaID OpenID Connect ของกรมการปกครอง และระบบรหัสผ่าน PIN 6 หลักที่ผ่านการเข้ารหัสทางเดียว (Hashing) นอกจากนี้ยังมีการรักษาความปลอดภัย API ด้วยการตรวจสอบ Device Pairing โดยหากมีอุปกรณ์ที่ยังไม่ได้จับคู่ส่งข้อมูลเข้ามา เซิร์ฟเวอร์จะปฏิเสธด้วยรหัส HTTP 409 Conflict ทันที

2.10 สถาปัตยกรรมฐานข้อมูลเชิงสัมพันธ์

เพื่อรักษาความสอดคล้องและความถูกต้องสมบูรณ์ของข้อมูลทางการแพทย์ (Data Integrity) ระบบได้ออกแบบโครงสร้างข้อมูลตามโมเดลเชิงสัมพันธ์ ประกอบด้วย 8 เอนทิตีหลัก ได้แก่ `Patient`, `Device`, `Vital`, `Telemetry`, `Triage`, `Alert`, `Queue`, และ `Nurse` ซึ่งมีการเชื่อมโยงความสัมพันธ์ด้วย Foreign Keys และการจัดทำ Index เพื่อรองรับการสืบค้นข้อมูลสัญญาณชีพย้อนหลังได้อย่างรวดเร็ว

2.11 การออกแบบโครงสร้างทางวิศวกรรม 3 มิติ

ตัวเรือนนาฬิกาได้รับการออกแบบผ่านโปรแกรม FreeCAD แบบพารามิเตอร์ และขึ้นรูปด้วยเทคโนโลยีการพิมพ์ 3 มิติแบบ FDM (Fused Deposition Modeling) โดยใช้วัสดุ PETG (Polyethylene Terephthalate Glycol) ซึ่งมีคุณสมบัติทนต่อแรงกระแทก ยืดหยุ่น ทนต่อความชื้นและเหงื่อของผู้สวมใส่ และมีความปลอดภัยต่อการสัมผัสผิวหนัง (Skin-Safe)

2.12 งานวิจัยที่เกี่ยวข้อง (Related Literature & Studies)

คณะผู้จัดทำได้ศึกษาและทบทวนวรรณกรรมที่เกี่ยวข้องกับการพัฒนาอุปกรณ์สวมใส่ติดตามสัญญาณชีพ ระบบ AI Triage และระบบจัดการคิวในโรงพยาบาล ดังแสดงการเปรียบเทียบในตารางที่ 2.3

ตารางที่ 2.3 สรุปและเปรียบเทียบผลการศึกษางานวิจัยที่เกี่ยวข้องกับโครงงาน

ผู้วิจัย / ปีที่พิมพ์ | หัวข้องานวิจัย / ระบบที่พัฒนา | เทคโนโลยีที่ใช้ | ผลการวิจัย / จุดเด่น | การนำมาประยุกต์ใช้ในโครงงาน
Rady et al. (1994) | การประเมินดัชนีช็อก (Shock Index) ในผู้ป่วยวิกฤต | สรีรวิทยาทางการแพทย์ / การวิเคราะห์ทางสถิติ | ค่า SI > 0.9 มีความไวสูงมากในการบ่งชี้ภาวะช็อก | ใช้เป็นเกณฑ์หลักในการคำนวณและแจ้งเตือนภาวะวิกฤต
Kim et al. (2022) | ระบบติดตามสัญญาณชีพไร้สายในหอผู้ป่วย | Wireless Vital Sign Sensors / Real-time System | ลดเวลาการตรวจพบอาการทรุดลงของผู้ป่วยได้อย่างมีนัยสำคัญ | ใช้เป็นแนวทางสถาปัตยกรรมการเฝ้าระวังผู้ป่วยนอก
Awadalla et al. (2021) | แพลตฟอร์ม IoT สำหรับการดูแลสุขภาพทางไกล | IoT Microcontroller / Cloud Web Dashboard | เว็บ Dashboard แสดงผลเรียลไทม์ช่วยให้การติดตามมีประสิทธิภาพ | ใช้เป็นแนวทางการพัฒนา Web Dashboard บน Next.js
Khan et al. (2024) | การทบทวนวรรณกรรมการติดตามสัญญาณชีพด้วย IoT | PPG Sensor / Microcontroller / Cloud Platform | PPG เหมาะสมที่สุดสำหรับ Smart Wearables ทางการแพทย์ | นำมาใช้เลือกโมดูล MAX32664 และ MAX30102
Levin et al. (2018) | Machine Learning สำหรับการคัดแยกผู้ป่วย ESI | Random Forest / NLP Chief Complaint | ML ช่วยเพิ่มความแม่นยำในการคัดแยกผู้ป่วยฉุกเฉิน | นำมาใช้เป็นแนวทาง AI Triage ร่วมกับ NLP TF-IDF
Mubashir et al. (2013) | การสำรวจเทคนิคการตรวจจับการหกล้ม | Wearable Accelerometer / Multi-stage FSM | การตรวจจับแบบหลายขั้นตอนช่วยลด False Alarms ได้ดีเยี่ยม | นำมาใช้ออกแบบ State Machine Fall Detection
คณะผู้จัดทำ (โครงงานนี้) | ระบบอุปกรณ์สวมใส่ติดตามสัญญาณชีพและเว็บแอปคัดแยกผู้ป่วยอัจฉริยะ | ESP32-C3 / MAX32664 / MPU6050 / Next.js / AI Triage / ThaID | บูรณาการ Vital Signs, Multi-stage Fall, AI Triage Human-in-the-loop, และ Dynamic Queue | ระบบต้นแบบบูรณาการครบวงจรสำหรับโรงพยาบาลอัจฉริยะ

บทที่ 3
วิธีดำเนินงาน

ในบทนี้จะกล่าวถึงขั้นตอนและระเบียบวิธีดำเนินงานในการวิจัยและพัฒนาระบบอุปกรณ์สวมใส่เพื่อการติดตามสุขภาพและเว็บแอปพลิเคชันคัดแยกผู้ป่วยอัจฉริยะสำหรับการจัดการคิวผู้ป่วยนอกอย่างละเอียด ครอบคลุมการวิเคราะห์ความต้องการ สถาปัตยกรรมระบบ การออกแบบฮาร์ดแวร์ การพัฒนาเฟิร์มแวร์ การออกแบบฐานข้อมูล การพัฒนาโมดูล AI Triage และเว็บแอปพลิเคชัน ตลอดจนระเบียบวิธีทดสอบระบบ

3.1 ขั้นตอนการดำเนินงานโดยรวม (Overall Methodology)

การดำเนินโครงงานใช้ระเบียบวิธีการพัฒนาเชิงวนซ้ำแบบสร้างต้นแบบ (Prototyping & Agile Development Lifecycle) โดยแบ่งออกเป็น 5 ระยะหลัก:

1. ระยะที่ 1: การศึกษาและรวบรวมข้อมูลความต้องการ (Requirements Analysis) — ศึกษากระบวนการคัดกรอง OPD, มาตรฐานสัญญาณชีพ, ระบบคัดแยก 5 ระดับ, กฎหมาย PDPA, และกำหนดข้อกำหนดเชิงเทคนิค

2. ระยะที่ 2: การออกแบบสถาปัตยกรรมและวงจรระบบ (System & Hardware Design) — ออกแบบผังวงจรอิเล็กทรอนิกส์, ออกแบบตัวเรือน 3 มิติผ่าน FreeCAD, ออกแบบฐานข้อมูล 8 ตาราง และ Use Case Diagram

3. ระยะที่ 3: การประกอบและพัฒนาเฟิร์มแวร์ (Hardware & Firmware Implementation) — ประกอบวงจรต้นแบบ, พัฒนาเฟิร์มแวร์ ESP32-C3, อัลกอริทึม SQI, Skin-Contact, Multi-stage Fall Detection, และ Battery LUT

4. ระยะที่ 4: การพัฒนาระบบ AI และเว็บแอปพลิเคชัน (AI & Software Implementation) — พัฒนาโมดูล AI-assisted Triage (NLP/Rules), หน้าจอกระดานพยาบาล (Nurse Dashboard), บัตรคิวดิจิทัล, และระบบความปลอดภัย ThaID/PIN

5. ระยะที่ 5: การทดสอบและประเมินประสิทธิภาพ (System Integration & Evaluation) — ทดสอบความแม่นยำเซนเซอร์เทียบเครื่องมือแพทย์, ทดสอบ Fall Detection, ประเมิน Confusion Matrix ของ AI, วัดความหน่วงเครือข่าย, และประเมินความพึงพอใจของผู้ใช้งาน 30 คน

3.2 การวิเคราะห์ความต้องการและการออกแบบสถาปัตยกรรมระบบ

ระบบได้รับการวิเคราะห์ความต้องการเชิงฟังก์ชัน (Functional Requirements) เช่น การวัดสัญญาณชีพแบบเรียลไทม์, การแจ้งเตือนเหตุหกล้ม, การประเมิน AI Triage 5 ระดับพร้อมเหตุผล, การยืนยันผลโดยพยาบาล, การปรับลำดับคิวอัตโนมัติ, และการดูบัตรคิวผ่านสมาร์ตโฟน และความต้องการเชิงไม่เชิงฟังก์ชัน (Non-Functional Requirements) เช่น ความหน่วงในการส่งข้อมูลไม่เกิน 5 วินาที, ความคลาดเคลื่อนสัญญาณชีพไม่เกิน ±5%, และการเข้ารหัสความปลอดภัยตามมาตรฐาน PDPA

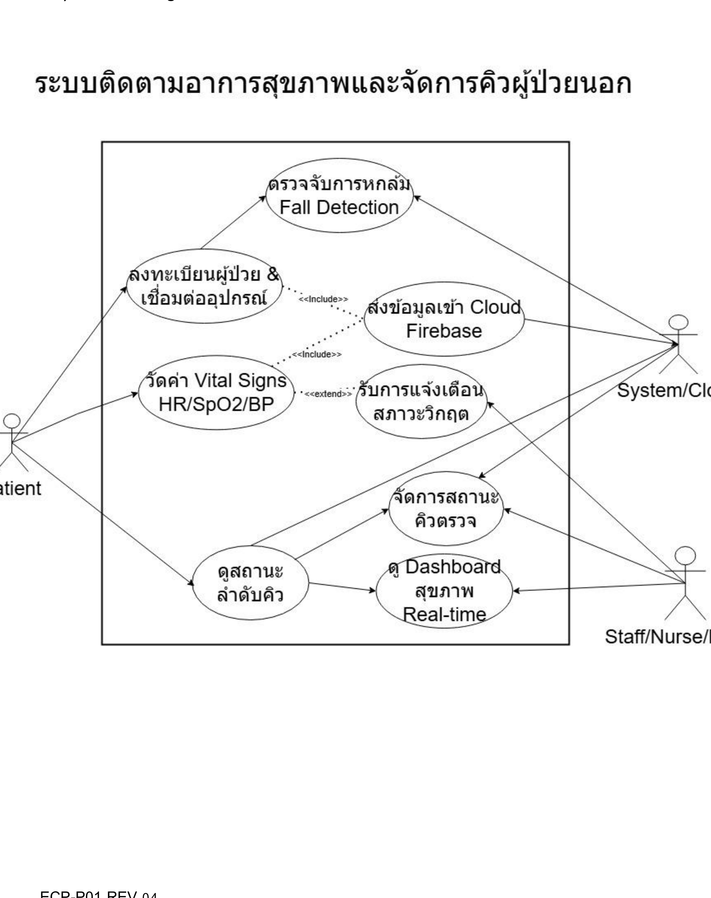
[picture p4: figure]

รูปที่ 3.1 แผนภาพ Use Case Diagram และสถาปัตยกรรมระบบรวม

3.3 การออกแบบและพัฒนาฮาร์ดแวร์อุปกรณ์สวมใส่ Smartwatch

การเชื่อมต่อระหว่างบอร์ด Seeed Studio XIAO ESP32-C3 กับโมดูลเซนเซอร์และอุปกรณ์ต่อพ่วง แสดงรายละเอียดการกำหนดขาพินในตารางที่ 3.1

ตารางที่ 3.1 การเชื่อมต่อพินระหว่าง ESP32-C3 กับโมดูลเซนเซอร์และอุปกรณ์ต่อพ่วง

อุปกรณ์ / โมดูล | ขาเชื่อมต่อ (Pin Name) | ขาบนบอร์ด ESP32-C3 | โปรโตคอล / หน้าที่การทำงาน
MAX32664 (Bio-Hub) | SDA / SCL | GPIO 4 / GPIO 5 | I2C Bus (ส่งผ่านข้อมูลสัญญาณชีพ HR/SpO2/BP)
MAX32664 (Bio-Hub) | RSTN / MFIO | GPIO 3 / GPIO 2 | Reset และ Data Ready Handshake Interrupt
MPU6050 (IMU) | SDA / SCL / INT | GPIO 4 / GPIO 5 / GPIO 1 | I2C Bus & Motion/Fall Interrupt Trigger
Round LCD (GC9A01) | SCL (SCK) / SDA (MOSI) | GPIO 8 / GPIO 10 | Hardware SPI Interface (ส่งข้อมูลภาพ)
Round LCD (GC9A01) | DC / CS / RST | GPIO 6 / GPIO 7 / GPIO 9 | Data/Command, Chip Select, Display Reset
Battery ADC Divider | V_SENSE (100k/100k) | GPIO 0 (ADC1_CH0) | ตรวจวัดแรงดันแบตเตอรี่ LiPo (ช่วง 3.0–4.2V)
Power Management | 3.3V / GND / BAT | 3V3 / GND / BAT+ | ระบบจ่ายแรงดันไฟฟ้าและวงจรชาร์จ LiPo 3.7V

การตรวจวัดแรงดันแบตเตอรี่ใช้วงจรแบ่งแรงดัน (Voltage Divider) ความต้านทาน R1 = 100kΩ และ R2 = 100kΩ เพื่อลดทอนแรงดันแบตเตอรี่สูงสุด 4.2V ให้อยู่ในช่วงไม่เกิน 2.1V ก่อนป้อนเข้าสู่ช่อง ADC โดยคำนวณแรงดันจริงได้จากสมการ (3.1)

V_(bat) =ADC_(val) ×(3.3/4095)×((R_1 +R_2)/(R_2))=ADC_(val) ×(3.3/4095)×2 (3.1)

รูปที่ 3.2 โมเดล 3D CAD ตัวเรือนนาฬิกา Smartwatch (SmartWatchV13 Comparison)

3.4 การพัฒนาเฟิร์มแวร์ระบบสมองกลฝังตัวบน ESP32-C3

การทำงานของเฟิร์มแวร์บนตัวอุปกรณ์สวมใส่ถูกควบคุมด้วยเครื่องสถานะจำกัด (Finite State Machine: FSM) เพื่อจัดการลำดับการทำงานตั้งแต่การเริ่มต้นระบบ การเชื่อมต่อ Wi-Fi การตรวจสอบเซนเซอร์ และการส่งข้อมูล Telemetry ดังแสดงในรูปที่ 3.3

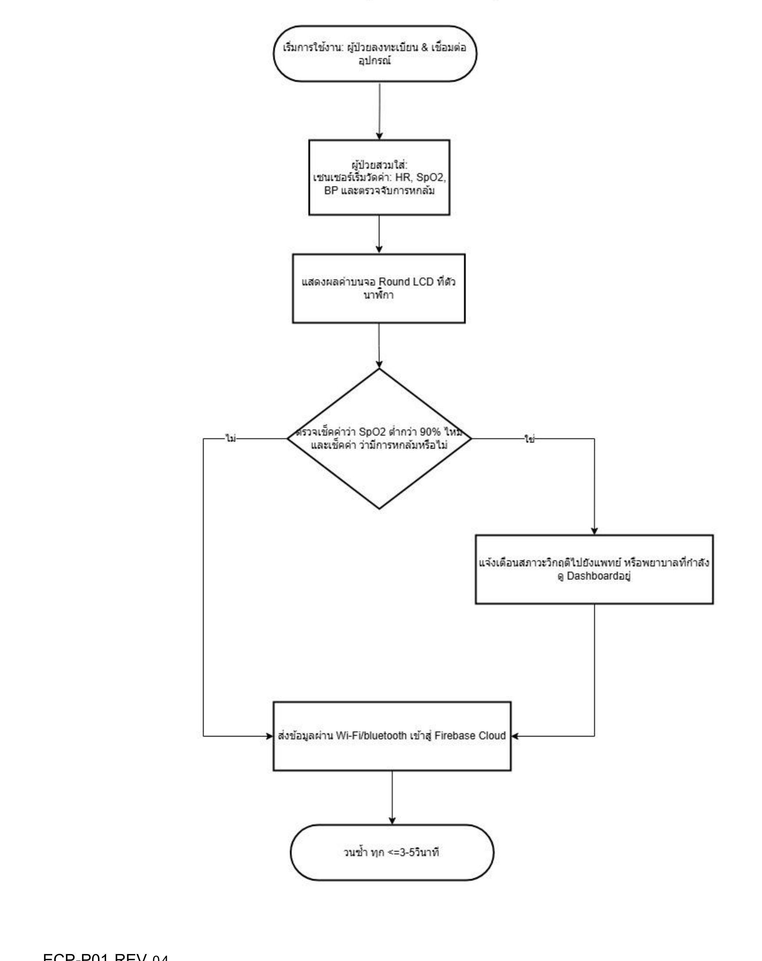
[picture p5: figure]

รูปที่ 3.3 ผังการทำงานของเฟิร์มแวร์ฮาร์ดแวร์บน ESP32-C3 (Hardware Flowchart)

เฟิร์มแวร์ได้บรรจุอัลกอริทึมการประมวลผลสัญญาณบนขอบเครือข่าย (Edge Processing) ได้แก่:

1) Skin-Contact Detection: ตรวจสอบความเข้มแสงสะท้อนต่ำสุด (Raw IR Amplitude > 10,000 counts) หากผู้ป่วยถอดสายรัดข้อมือออก ระบบจะระงับการบันทึกค่าและเปลี่ยนสถานะเป็น NO_CONTACT ทันที

2) Signal Quality Index (SQI): ตรวจสอบความสม่ำเสมอของรูปคลื่น PPG และปฏิเสธค่า SpO2 หลอกที่ระดับ 70.0% ซึ่งเป็นค่า Unready Floor ของชิปเซนเซอร์

3) 20-Sample Sliding Window: ทำการเก็บตัวอย่างสัญญาณชีพที่ความถี่ 500 ms ต่อตัวอย่าง และเฉลี่ยผลรวม 20 ตัวอย่างเพื่อให้ได้ค่าที่มีความเที่ยงตรงสูงก่อนส่งขึ้นสู่เซิร์ฟเวอร์
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

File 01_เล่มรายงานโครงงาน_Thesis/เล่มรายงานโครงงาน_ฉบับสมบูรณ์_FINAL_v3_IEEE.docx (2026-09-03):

ระบบอุปกรณ์สวมใส่ติดตามสุขภาพและเว็บแอปพลิเคชันเช็คคิวผู้ป่วยนอก

WEARABLE HEALTH MONITORING DEVICE AND OUTPATIENT QUEUE CHECK WEB APPLICATION

นายปรเมศว์ เดนนิส โฮค อาร์ริงตัน

นายธนกร สุภาวรรณชัย

ปริญญานิพนธ์นี้เป็นส่วนหนึ่งของการศึกษาตามหลักสูตรปริญญาวิศวกรรมศาสตรบัณฑิต

สาขาวิชาวิศวกรรมคอมพิวเตอร์

คณะวิศวกรรมศาสตร์ มหาวิทยาลัยเทคโนโลยีราชมงคลอีสาน วิทยาเขตขอนแก่น

พ.ศ. 2568

ลิขสิทธิ์ของคณะวิศวกรรมศาสตร์ มหาวิทยาลัยเทคโนโลยีราชมงคลอีสาน

ระบบอุปกรณ์สวมใส่ติดตามสุขภาพและเว็บแอปพลิเคชันเช็คคิวผู้ป่วยนอก

นายปรเมศว์ เดนนิส โฮค อาร์ริงตัน

นายธนกร สุภาวรรณชัย

ปริญญานิพนธ์นี้เป็นส่วนหนึ่งของการศึกษาตามหลักสูตรปริญญาวิศวกรรมศาสตรบัณฑิต

สาขาวิชาวิศวกรรมคอมพิวเตอร์

คณะวิศวกรรมศาสตร์ มหาวิทยาลัยเทคโนโลยีราชมงคลอีสาน วิทยาเขตขอนแก่น

พ.ศ. 2568

ลิขสิทธิ์ของคณะวิศวกรรมศาสตร์ มหาวิทยาลัยเทคโนโลยีราชมงคลอีสาน

Wearable Health Monitoring Device and Outpatient Queue Check Web Application

Poramate Dennis Hoke Arrington

Thanakorn Suphawanchai

A Report Submitted in Partial Fulfillment of the Requirements for

the Degree of Bachelor of Engineering

Department of Computer Engineering

Faculty of Engineering

Rajamangala University of Technology Isan, Khon Kaen Campus

2025

© Faculty of Engineering, Rajamangala University of Technology Isan

หัวข้อปริญญานิพนธ์ : ระบบอุปกรณ์สวมใส่ติดตามสุขภาพและเว็บแอปพลิเคชันเช็คคิวผู้ป่วยนอก
จัดทำโดย : นายปรเมศว์ เดนนิส โฮค อาร์ริงตัน
นายธนกร สุภาวรรณชัย
สาขาวิชา : วิศวกรรมคอมพิวเตอร์
ประธานที่ปรึกษา : อาจารย์ ดร.ปิยะนุช ตั้งกิตติพล
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

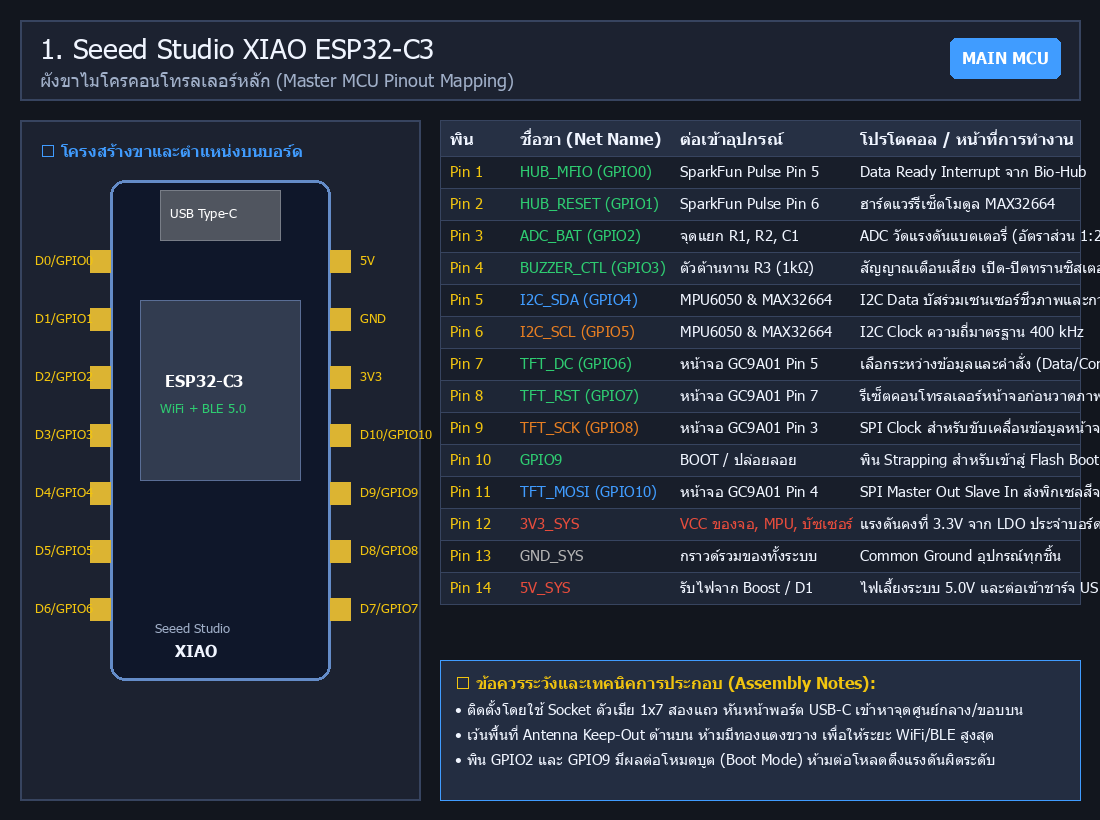
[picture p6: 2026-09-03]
02_ฮาร์ดแวร์และวงจร_Hardware/component_pinouts/01_xiao_esp32c3_pinout.png

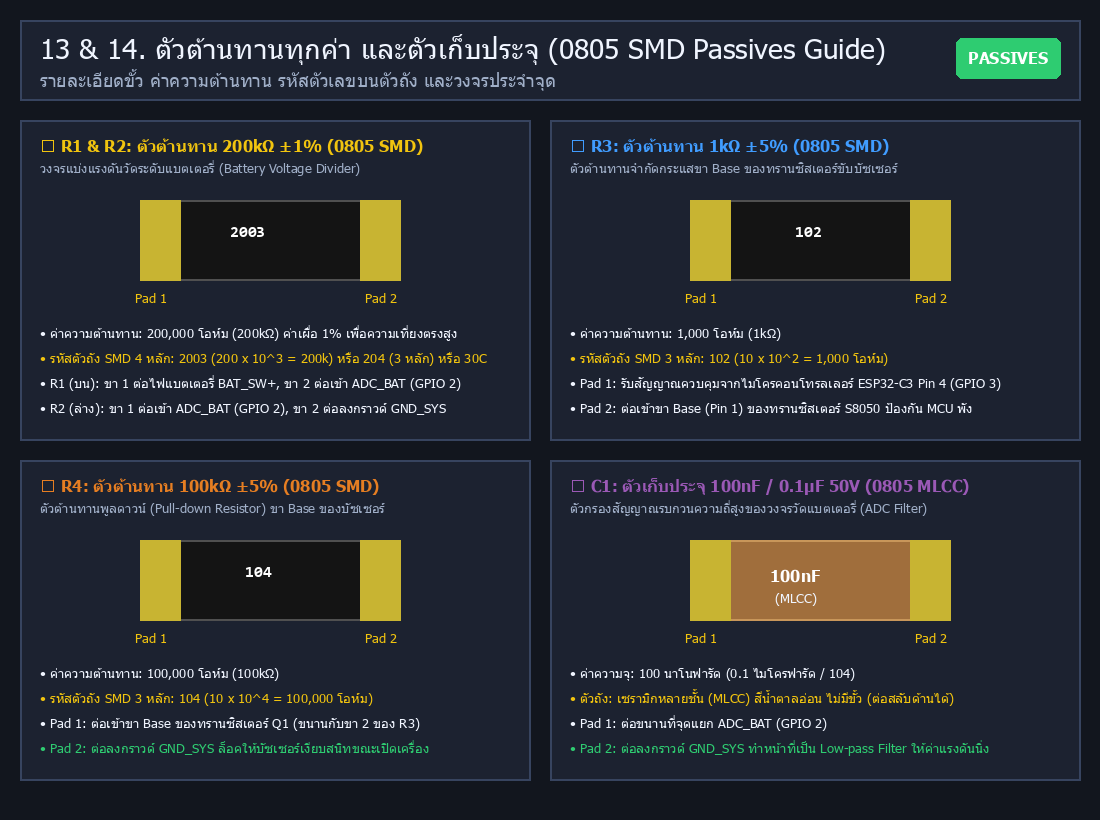
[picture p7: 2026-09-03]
02_ฮาร์ดแวร์และวงจร_Hardware/component_pinouts/07_SMD_Resistors_R1_R2_R3_R4_and_Capacitor_C1_Pinout.png

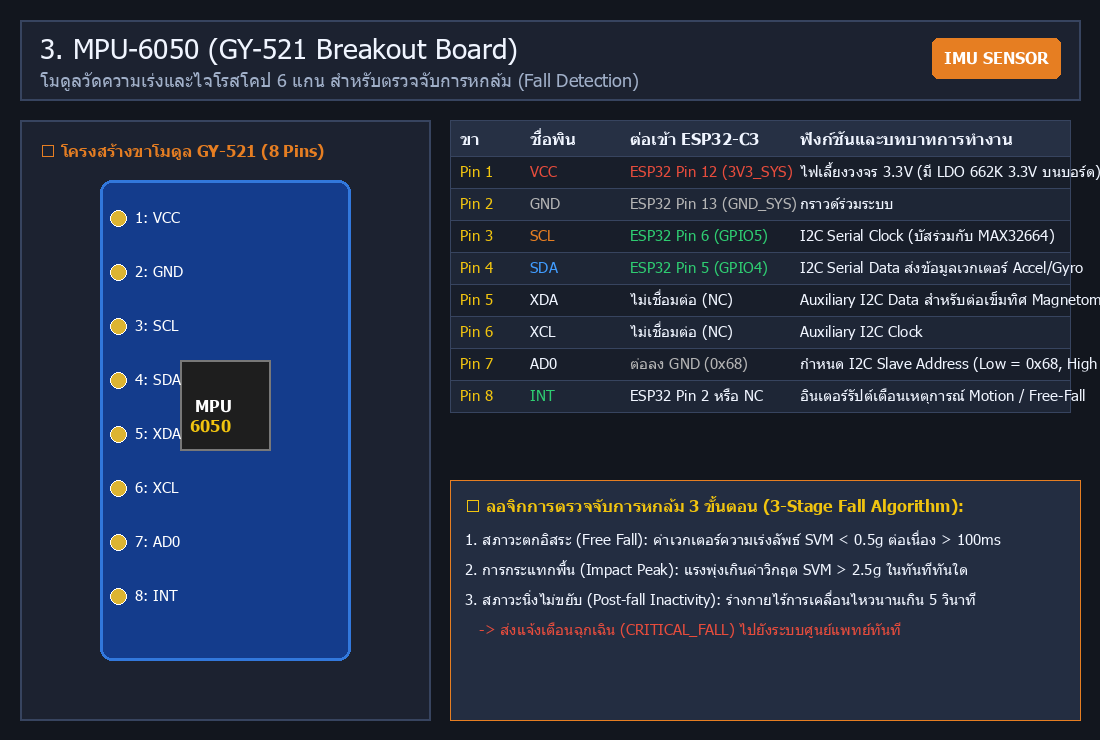
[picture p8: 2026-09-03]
02_ฮาร์ดแวร์และวงจร_Hardware/component_pinouts/03_MPU6050_GY521_Pinout.png

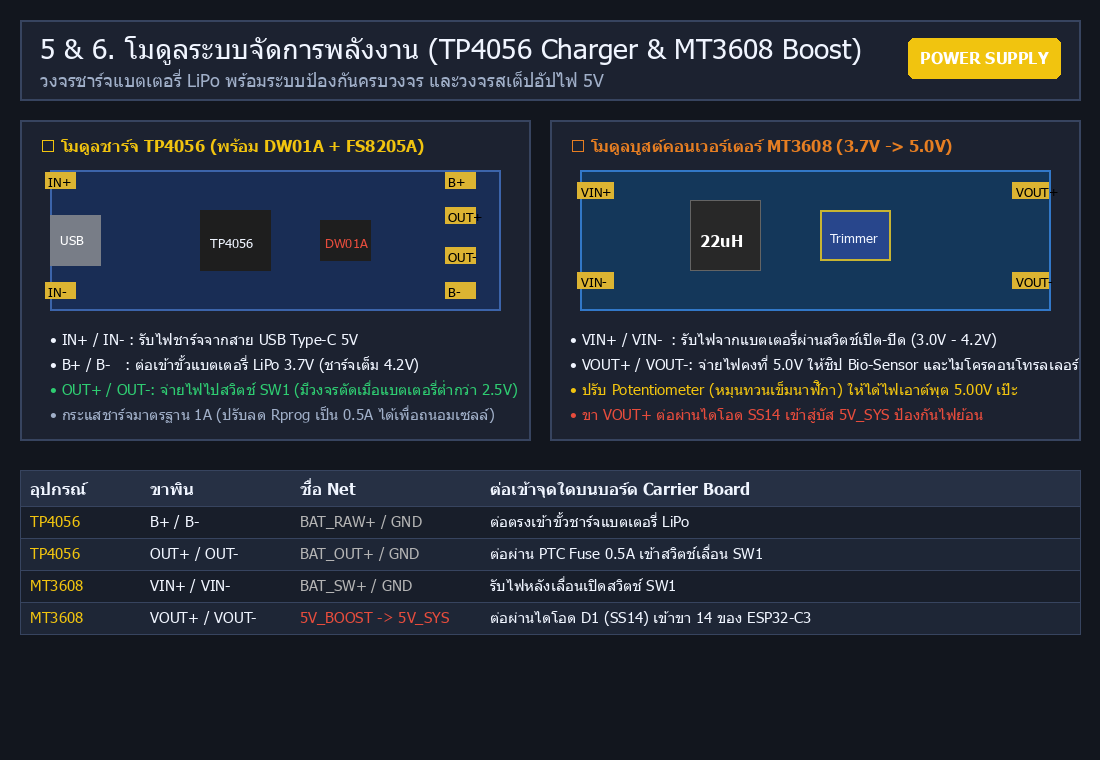
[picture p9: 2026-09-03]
02_ฮาร์ดแวร์และวงจร_Hardware/component_pinouts/05_Power_Modules_TP4056_MT3608_Pinout.png

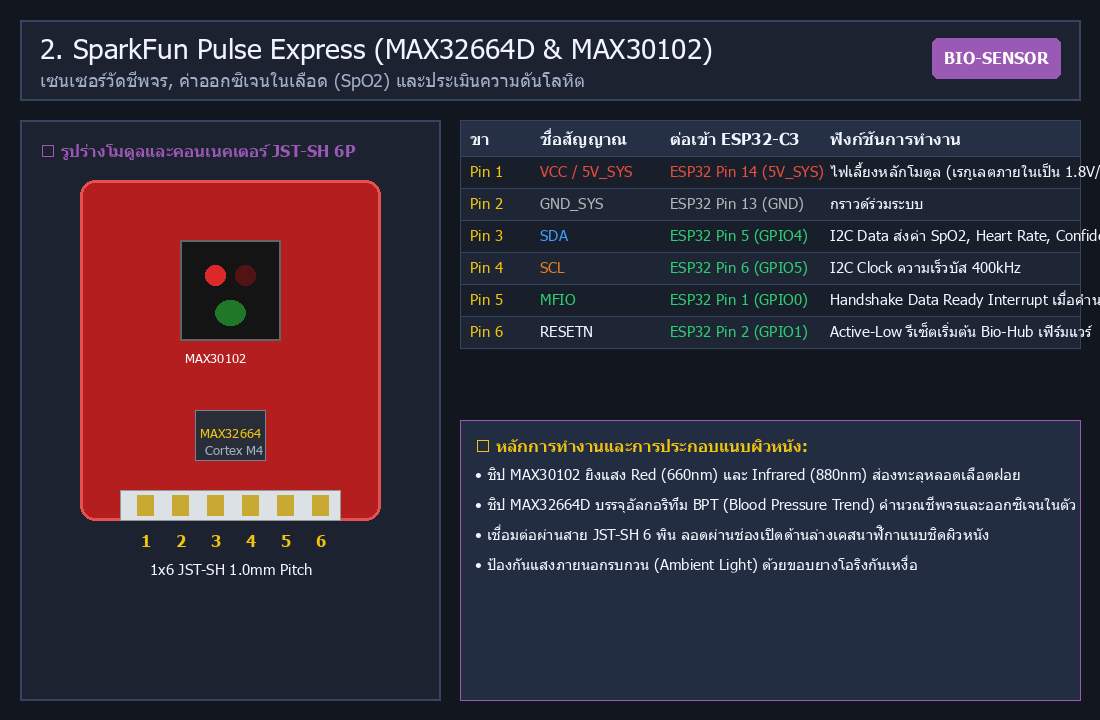
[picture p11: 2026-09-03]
02_ฮาร์ดแวร์และวงจร_Hardware/component_pinouts/02_Pulse_Express_MAX32664_MAX30102_Pinout.png

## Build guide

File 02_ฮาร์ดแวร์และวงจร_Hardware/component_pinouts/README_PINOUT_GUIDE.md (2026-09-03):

# 📌 คู่มือแผนผังขา (Pinout) และรูปภาพอุปกรณ์ทุกตัว ทุกค่า (Complete Hardware Pinout Guide)
## โครงการ SmartWatch Carrier Board v1.0 (อุปกรณ์สวมใส่ติดตามสุขภาพและระบบคิวผู้ป่วยนอก)

โฟลเดอร์นี้รวบรวม **รูปภาพแผนผังขา (Pinout Diagrams)** ความละเอียดสูงระดับโปสเตอร์วิศวกรรม, มาร์คกิ้งบนตัวถัง SMD, ขั้วต่อ (Polarity), และตารางจับคู่ขาสัญญาณทั้งหมด 17 ชิ้นส่วนของวงจร

---

### 📂 ไฟล์ภาพทั้งหมดในโฟลเดอร์นี้:
1. **[00_MASTER_PINOUT_CHEATSHEET.png](./00_MASTER_PINOUT_CHEATSHEET.png)** - โปสเตอร์รวมผังขาทุกอุปกรณ์ความละเอียดสูงพิเศษ 2260x3380 px
2. **[01_Official_Seeed_XIAO_Wiki_Pinout.png](./01_Official_Seeed_XIAO_Wiki_Pinout.png)** - ผังขาทางการจาก Seeed Studio Wiki
3. **[01_XIAO_ESP32C3_Pinout.png](./01_xiao_esp32c3_pinout.png)** - ผังขา Seeed Studio XIAO ESP32-C3 พร้อมจุดต่อ SmartWatch
4. **[02_Pulse_Express_MAX32664_MAX30102_Pinout.png](./02_Pulse_Express_MAX32664_MAX30102_Pinout.png)** - ขั้วต่อ JST-SH 6P เซนเซอร์ชีพจรและ SpO2
5. **[03_MPU6050_GY521_Pinout.png](./03_MPU6050_GY521_Pinout.png)** - ผังขา 8 พิน โมดูลตรวจจับการหกล้ม MPU-6050
6. **[04_GC9A01_Round_TFT_7Pin_Pinout.png](./04_GC9A01_Round_TFT_7Pin_Pinout.png)** - ผังขา 7 พิน SPI หน้าจอแสดงผลทรงกลม GC9A01
7. **[05_TP4056_LiPo_Charger_Module.png](./05_TP4056_LiPo_Charger_Module.png)** - โมดูลชาร์จ LiPo TP4056 พร้อมวงจรป้องกัน DW01A
8. **[06_MT3608_5V_Boost_Converter.png](./06_MT3608_5V_Boost_Converter.png)** - โมดูลบูสต์สเต็ปอัป 3.7V เป็น 5.0V MT3608
9. **[07_S8050_NPN_Transistor_SOT23.png](./07_S8050_NPN_Transistor_SOT23.png)** - ทรานซิสเตอร์ S8050 (มาร์คกิ้ง J3Y บนตัวถัง SOT-23)
10. **[08_Active_Buzzer_3.3V.png](./08_Active_Buzzer_3.3V.png)** - บัซเซอร์ 3.3V พร้อมบอกขั้วบวก (+) และขั้วลบ (-)
11. **[09_SS14_Schottky_Diode_SMA.png](./09_SS14_Schottky_Diode_SMA.png)** - ไดโอด SS14 พร้อมตำแหน่งแถบสีขาวขั้วลบ Cathode
12. **[10_PTC_Resettable_Fuse_0.5A_1206.png](./10_PTC_Resettable_Fuse_0.5A_1206.png)** - ฟิวส์คืนสภาพ 0.5A ขนาด 1206 SMD
13. **[11_PCM12_SPDT_Slide_Switch.png](./11_PCM12_SPDT_Slide_Switch.png)** - สวิตช์เลื่อนเปิด-ปิด SPDT PCM12 SMD
14. **[12_JST_PH_2Pin_Battery_Connector.png](./12_JST_PH_2Pin_Battery_Connector.png)** - ขั้วต่อสายไฟแบตเตอรี่ LiPo แดง (+)/ดำ (-)
15. **[13_Resistor_R1_200k_0805.png](./13_Resistor_R1_200k_0805.png)** - ตัวต้านทาน R1: 200kΩ ±1% (รหัส 2003 / 204)
16. **[14_Resistor_R2_200k_0805.png](./14_Resistor_R2_200k_0805.png)** - ตัวต้านทาน R2: 200kΩ ±1% (รหัส 2003 / 204)
17. **[15_Resistor_R3_1k_0805.png](./15_Resistor_R3_1k_0805.png)** - ตัวต้านทาน R3: 1kΩ ±5% (รหัส 102)
18. **[16_Resistor_R4_100k_0805.png](./16_Resistor_R4_100k_0805.png)** - ตัวต้านทาน R4: 100kΩ ±5% (รหัส 104)
19. **[17_Capacitor_C1_100nF_0805.png](./17_Capacitor_C1_100nF_0805.png)** - ตัวเก็บประจุ C1: 100nF 50V (MLCC 0805 สีน้ำตาล)
20. **[index.html](./index.html)** - โปรแกรมเปิดดูผังขาแบบโต้ตอบ (Interactive Pinout Viewer) ในเบราว์เซอร์

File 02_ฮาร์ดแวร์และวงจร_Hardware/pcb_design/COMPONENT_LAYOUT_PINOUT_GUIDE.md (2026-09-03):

# 📖 COMPONENT LAYOUT & PINOUT READING GUIDE
## คู่มือการอ่านไฟล์ ผังการจัดวางอุปกรณ์ และลำดับขั้นตอนการประกอบบอร์ด SmartWatch v1.0

---

## 1. 🗺️ แผนผังโซนอุปกรณ์ฉบับสมบูรณ์ (Spatial Zoning Map)

บอร์ด PCB วงกลมขนาด **Ø 44.0 mm** ถูกแบ่งพื้นที่จัดวางอุปกรณ์ออกเป็น 6 โซนอิสระเพื่อป้องกันการชนกัน (Zero Footprint Collision) 100%:

```
                          [ ขอบบนสุด: R <= 19.2 mm ]
     ┌──────────────────────────────────────────────────────────────────┐
     │                      ANTENNA KEEP-OUT ZONE                       │
     │      (X = 93.5 ถึง 106.5 mm, Y = 81.5 ถึง 85.5 mm : ปลอดโลหะ)    │
     ├──────────────────────────────────┬───────────────────────────────┤
     │  🔴 โซนบนซ้าย: ระบบแจ้งเตือนเสียง│  🔵 โซนบนขวา: วัดระดับแบตเตอรี่│
     │  • BZ1 : บัซเซอร์ 3.3V (90, 85.5)│  • R1 : ตัวต้านทาน 200kΩ (106, 86.5) │
     │  • Q1  : ทรานซิสเตอร์ SOT-23     │  • R2 : ตัวต้านทาน 200kΩ (106, 89.5) │
     │  • R3  : 1kΩ  • R4 : 100kΩ       │  • C1 : ตัวเก็บประจุ 100nF (106, 92.5)│
     ├──────────────────────────────────┴───────────────────────────────┤
     │               🟢 โซนกึ่งกลางบอร์ด: หน่วยประมวลผลหลัก              │
     │            • U1 : Seeed Studio XIAO ESP32-C3 (100, 95.0)        │
     │              (ซ็อคเก็ตตัวเมีย 2 แถว กว้าง 15.4 mm)               │
     ├──────────────────────────────────┬───────────────────────────────┤
     │  🟡 โซนซ้าย: ตรวจจับการล้ม       │  🟣 โซนขวา: วัดชีพจรและออกซิเจน│
     │  • U3 : MPU6050 6-Axis IMU       │  • U2_CONN : Pulse Express     │
     │    (ขั้วต่อ 1x8 พิน X = 86.0 mm) │    (ขั้วต่อ JST-SH 6P X = 114mm)│
     ├──────────────────────────────────┴───────────────────────────────┤
     │              ⚪ หน้าบน (Top Layer): ขั้วต่อหน้าจอแสดงผล           │
     │            • DISP1 : GC9A01 240x240 Round TFT (100, 106.5)      │
     │              (ขั้วต่อ 1x7 พิน ระยะ Pitch 2.54 mm)               │
     ├──────────────────────────────────────────────────────────────────┤
     │           🟤 โซนล่างสุด: สวิตช์และระบบป้องกันไฟฟ้า (Y = 112.5)    │
     │  • F1  : ฟิวส์ตัดตอน PTC 0.5A 1206 (X = 89.5 mm)                 │
     │  • SW1 : สวิตช์เลื่อนเปิด-ปิด SPDT PCM12 (X = 95.0 mm)           │
     │  • J1  : ขั้วเสียบแบตเตอรี่ JST-PH 2-Pin 2.0mm (X = 101.0 mm)    │
     │  • D1  : ไดโอดช็อตต์กี SS14 SMA (X = 107.5 mm)                   │
     └──────────────────────────────────────────────────────────────────┘
```

---

## 2. 📌 ตารางจับคู่ขาพินทั้งหมด (Pin-to-Pin Interconnection Table)

| ขาบน MCU (XIAO ESP32-C3) | ชื่อสัญญาณวงจร (Net Name) | ต่อไปยังขาอุปกรณ์ปลายทาง (Destination Pins) | ความกว้างเส้น | เลเยอร์ที่เดินสาย |
| :---: | :---: | :--- | :---: | :---: |
| **Pin 1 (GPIO0 / D0)** | `HUB_MFIO` | `U2_CONN` (Pulse Express Pin 5) | 0.35 mm | Bottom (B.Cu) |
| **Pin 2 (GPIO1 / D1)** | `HUB_RESET` | `U2_CONN` (Pulse Express Pin 6) | 0.35 mm | Bottom (B.Cu) |
| **Pin 3 (GPIO2 / A2)** | `ADC_BAT` | กึ่งกลางระหว่าง `R1`(Pin 2), `R2`(Pin 1) และ `C1`(Pin 1) | 0.35 mm | Bottom (B.Cu) |
| **Pin 4 (GPIO3 / D3)** | `BUZZER_CTL` | `R3` (1kΩ Pin 1) $\rightarrow$ ขา Base ของ `Q1` | 0.35 mm | Bottom (B.Cu) |
| **Pin 5 (GPIO4 / D4)** | `I2C_SDA` | `U3` (MPU6050 Pin 4) และ `U2_CONN` (Pulse Express Pin 3) | 0.35 mm | Top (F.Cu) |
| **Pin 6 (GPIO5 / D5)** | `I2C_SCL` | `U3` (MPU6050 Pin 3) และ `U2_CONN` (Pulse Express Pin 4) | 0.35 mm | Top (F.Cu) |
| **Pin 7 (GPIO6 / D6)** | `TFT_DC` | `DISP1` (GC9A01 Display Pin 5: DC) | 0.35 mm | Bottom (B.Cu) |
| **Pin 8 (GPIO7 / D7)** | `TFT_RST` | `DISP1` (GC9A01 Display Pin 7: RST) | 0.35 mm | Top (F.Cu) |
| **Pin 9 (GPIO8 / D8)** | `TFT_SCK` | `DISP1` (GC9A01 Display Pin 3: SCL/SCK) | 0.35 mm | Bottom (B.Cu) |
| **Pin 11 (GPIO10 / D10)**| `TFT_MOSI` | `DISP1` (GC9A01 Display Pin 4: SDA/MOSI) | 0.35 mm | Top (F.Cu) |
| **Pin 12 (3V3 Out)** | `3V3_SYS` | `DISP1`(Pin 1), `U3`(Pin 1: VCC), `BZ1`(Pin 1: ขาบวก) | 0.45 mm | Bottom (B.Cu) |
| **Pin 13 (GND)** | `GND_SYS` | กราวด์รวมของทุกโมดูล (`DISP1`, `U3`, `U2_CONN`, `Q1`, `R4`, `R2`, `C1`, `J1`) | 0.55 mm | Bottom (B.Cu) |
| **Pin 14 (5V In)** | `5V_SYS` | `D1` (ไดโอด Pin 2: Cathode) และ `U2_CONN` (Pulse Express Pin 1: VCC) | 0.75 mm | Bottom (B.Cu) |

---

## 3. 🛠️ ลำดับขั้นตอนการบัดกรีประกอบบอร์ด (Soldering Assembly Sequence)

เพื่อให้ประกอบได้ง่ายและไม่ติดขัด แนะนำให้บัดกรีตามลำดับความสูงของอุปกรณ์ดังนี้:

### ขั้นตอนที่ 1: บัดกรีอุปกรณ์ SMD ขนาดเล็กก่อน (เตี้ยสุด)
1. บัดกรีตัวต้านทานและตัวเก็บประจุ 0805: `R1`, `R2`, `R3`, `R4`, `C1`
2. บัดกรีทรานซิสเตอร์ SOT-23: `Q1` (S8050)
3. บัดกรีฟิวส์ 1206: `F1` (PTC 0.5A)
4. บัดกรีไดโอด SMA: `D1` (SS14) *(สังเกตแถบสีขาวขั้วลบ Cathode ให้หันเข้าหา Pin 14 ของ MCU)*
5. บัดกรีสวิตช์เลื่อน: `SW1` (PCM12)
6. บัดกรีขั้วต่อเซนเซอร์ชีพจร: `U2_CONN` (JST-SH 6-Pin SMD)

### ขั้นตอนที่ 2: บัดกรีขั้วต่อ Through-Hole ด้านหลัง (Bottom)
1. บัดกรีขั้วต่อซ็อคเก็ตตัวเมีย 1x7 สองแถว สำหรับเสียบโมดูล `U1` (XIAO ESP32-C3)
2. บัดกรีขั้วต่อตัวเมีย 1x8 สำหรับเสียบโมดูล `U3` (MPU6050)
3. บัดกรีขั้วต่อสายไฟแบตเตอรี่ `J1` (JST-PH 2.0mm)
4. บัดกรีบัซเซอร์ `BZ1` (Active Buzzer 3.3V)

### ขั้นตอนที่ 3: บัดกรีขั้วต่อหน้าจอด้านหน้า (Top Layer)
1. พลิกมาที่หน้าบน (F.Cu) บัดกรีขั้วต่อ 1x7 Pin Header สำหรับเสียบหน้าจอ `DISP1` (GC9A01)

---

## 4. ⚡ ขั้นตอนการทดสอบเปิดเครื่องครั้งแรก (First Power-On Checklist)
1. **ทดสอบความต้านทาน (Ohm Meter Check)**:
   - นำมัลติมิเตอร์วัดความต้านทานระหว่างขั้ว `3V3` กับ `GND` และระหว่าง `5V` กับ `GND`
   - ค่าความต้านทานจะต้องไม่เป็น $0\text{ }\Omega$ (ห้ามช็อตลงกราวด์)
2. **ทดสอบสวิตช์เปิด-ปิด (Switch Test)**:
   - เสียบแบตเตอรี่ LiPo 3.7V ที่ขั้ว `J1`
   - เมื่อเลื่อนสวิตช์ `SW1` ไปที่ตำแหน่ง ON ไฟแรงดันแบตเตอรี่ต้องผ่านฟิวส์และสวิตช์มาปรากฏที่ขา `BAT_SW+`
3. **ทดสอบการทำงานของ MCU และจอ**:
   - เสียบโมดูล XIAO ESP32-C3 และหน้าจอ GC9A01
   - อัปโหลดโค้ดทดสอบ SPI Display $\rightarrow$ หน้าปัดนาฬิกาจะสว่างและแสดงผลภาพกราฟิกทันทีครับ!
```

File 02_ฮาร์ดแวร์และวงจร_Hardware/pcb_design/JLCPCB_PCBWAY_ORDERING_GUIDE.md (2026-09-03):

# 🏭 JLCPCB & PCBWAY ORDERING SPECIFICATION & PROMPT GUIDE
> **คำแนะนำ:** เอกสารนี้รวบรวมพารามิเตอร์และขั้นตอนสำหรับนำไฟล์ `SmartWatch_Carrier_v1_Gerber.zip` ไปสั่งผลิตที่โรงงาน **JLCPCB**, **PCBWay** หรือโรงงานรับทำ PCB ชั้นนำ

---

## 1. 📋 ตารางพารามิเตอร์สำหรับกรอกหน้าเว็บสั่งผลิต (Parameters Checklist)

เมื่อคุณเข้าสู่หน้าสั่งซื้อของ [JLCPCB.com](https://jlcpcb.com) หรือ [PCBWay.com](https://pcbway.com) แล้วอัปโหลดไฟล์ **`SmartWatch_Carrier_v1_Gerber.zip`** ให้เลือกตั้งค่าพารามิเตอร์ตามตารางนี้:

| หัวข้อตั้งค่า (Option Name) | ค่าที่ต้องเลือก (Selected Value) | เหตุผลทางวิศวกรรม (Engineering Rationale) |
| :--- | :---: | :--- |
| **Base Material** | **FR-4** | วัสดุมาตรฐานฉนวนใยแก้ว แข็งแรง ทนความร้อนสูง |
| **Layers** | **2 Layers** | วงจร 2 หน้า (หน้าบนขับจอ, หน้าหลัง MCU & เซนเซอร์) |
| **Dimensions** | **44 mm × 44 mm** | ขนาดทรงกลม Ø 44.0 mm (ระบบจะตรวจจับจากไฟล์ Edge_Cuts อัตโนมัติ) |
| **PCB Qty** | **5 pcs** (หรือตามต้องการ) | จำนวนเริ่มต้นขั้นต่ำที่คุ้มราคาที่สุด |
| **Different Design** | **1 Design** | มี 1 แบบวงจร |
| **Delivery Format** | **Single PCB** | ส่งมอบเป็นชิ้นเดี่ยวตัดขอบกลม |
| **PCB Thickness** | **1.0 mm** (หรือ 1.2 mm) | **แนะนำ 1.0 mm** เพื่อให้ตัวเรือนนาฬิกาบางและเบาที่สุด |
| **PCB Color (Solder Mask)** | **Matte Black** (สีดำด้าน) หรือ **Green** (สีเขียว) | สีดำด้านจะดูหรูหราเข้ากับเคสสมาร์ทวอทช์ |
| **Silkscreen Color** | **White** (สีขาว) | ตัวหนังสือสีขาวตัดกับพื้นบอร์ดสีดำ อ่านขาง่าย คมชัด |
| **Surface Finish** | **HASL Lead-Free** (หรือ **ENIG**) | • **HASL Lead-Free**: บัดกรีง่าย ไร้สารตะกั่ว ปลอดภัยต่อการสวมใส่<br>• **ENIG (ชุบทองแท้)**: ผิวเรียบเนียนระดับพรีเมียม สวยงาม ทนทานต่อเหงื่อ |
| **Outer Lead Weight** | **1 oz** (35 µm) | ความหนาทองแดงมาตรฐาน รองรับกระแสไฟได้สูงถึง 2.0A สบายๆ |
| **Via Process** | **Tenting Vias** (หรือ Untented) | เคลือบหน้ากากปิดรูเวีย ป้องกันการลัดวงจร |
| **Min Hole Size / Drill** | **0.4 mm** | รูเจาะเวียขนาด 0.40 mm และรูขาอุปกรณ์ 0.85–0.90 mm |
| **Min Track / Spacing** | **6/6 mil (0.15 mm)** | ลายเส้นของเราออกแบบไว้ที่ 0.35 mm (13.8 mil) ซึ่งผ่านเกณฑ์โรงงานแบบเหลือเฟือ |
| **Edge Connector / Gold Fingers** | **No** | ไม่มีขั้วสล็อตเสียบการ์ด |
| **Castellated Holes** | **No** | ไม่มีรูกัดขอบ |
| **Confirm Production File** | **Yes** (แนะนำ) | ให้วิศวกรโรงงานส่งภาพตรวจก่อนเริ่มตัดแผ่น |

---

## 2. 📦 รายการไฟล์ภายในชุด Gerber ZIP (`SmartWatch_Carrier_v1_Gerber.zip`)

ภายในไฟล์ ZIP ประกอบด้วยไฟล์มาตรฐาน RS-274X และ Excellon ครบถ้วน 100%:

```
SmartWatch_Carrier_v1_Gerber.zip
 ├── SmartWatch_Carrier_v1-F_Cu.gtl         [เลเยอร์ทองแดงหน้าบน - Top Copper]
 ├── SmartWatch_Carrier_v1-B_Cu.gbl         [เลเยอร์ทองแดงหน้าหลัง - Bottom Copper]
 ├── SmartWatch_Carrier_v1-F_Mask.gts       [หน้ากากโซลเดอร์มาร์กหน้าบน - Top Solder Mask]
 ├── SmartWatch_Carrier_v1-B_Mask.gbs       [หน้ากากโซลเดอร์มาร์กหน้าหลัง - Bottom Solder Mask]
 ├── SmartWatch_Carrier_v1-F_SilkS.gto      [ลายสกรีนตัวหนังสือหน้าบน - Top Silkscreen]
 ├── SmartWatch_Carrier_v1-B_SilkS.gbo      [ลายสกรีนตัวหนังสือหน้าหลัง - Bottom Silkscreen]
 ├── SmartWatch_Carrier_v1-F_Paste.gtp      [เลเยอร์แผ่นสเตนซิลหน้าบน - Top Solder Paste]
 ├── SmartWatch_Carrier_v1-B_Paste.gbp      [เลเยอร์แผ่นสเตนซิลหน้าหลัง - Bottom Solder Paste]
 ├── SmartWatch_Carrier_v1-Edge_Cuts.gm1    [เส้นขอบตัดบอร์ดวงกลม Ø 44mm - Board Outline]
 └── SmartWatch_Carrier_v1.drl              [ไฟล์พิกัดและขนาดรูเจาะสว่าน - Excellon Drill File]
```

---

## 3. 📝 ข้อความสั่งผลิตแบบข้อกำหนดภาษาอังกฤษ (English Production Note)
หากโรงงานหรือระบบขอ **"Order Remark / Production Notes"** คุณสามารถคัดลอกข้อความนี้ไปใส่ได้ทันที:

```text
Dear Engineer,
Please manufacture this 2-layer round PCB according to the following specifications:
1. Board Outline: Circular shape Ø 44.0 mm, defined on Edge.Cuts layer.
2. Thickness: 1.0 mm FR-4 (Tg 130-140°C).
3. Surface Finish: HASL Lead-Free (or ENIG if selected).
4. Copper Weight: 1 oz (35 µm) outer layers.
5. Solder Mask: Matte Black. Silkscreen: White.
6. Minimum drill size: 0.40 mm (Vias), Component lead holes: 0.85 mm - 0.90 mm.
7. Clean all drill holes and ensure accurate circular routing along Edge.Cuts.
Thank you!
```

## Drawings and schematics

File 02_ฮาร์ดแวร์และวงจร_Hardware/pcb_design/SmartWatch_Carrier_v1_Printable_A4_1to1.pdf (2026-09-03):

# PAGE 1: BOTTOM COPPER LAYER (B.Cu) - MIRRORED

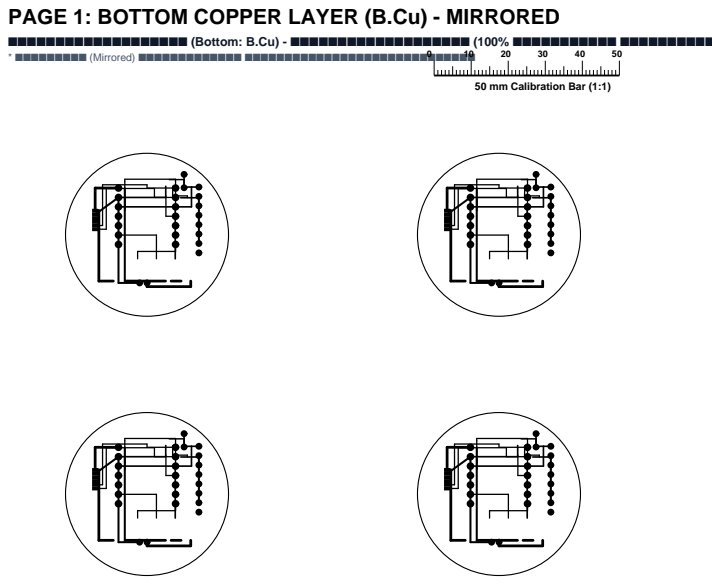
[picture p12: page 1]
■■■■■■■■■■■■■■■■■■■ (Bottom: B.Cu) - ■■■■■■■■■■■■■■■■■■■ (100% ■■■■■■■■■■■ ■■■■■■■■■■); * ■■■■■■■■■ (Mirrored) ■■■■■■■■■■■■■ ■■■■■■■■■■■■■■■■■■■■■■■■■■■■■ 0

50 mm Calibration Bar (1:1)

# PAGE 2: TOP COPPER LAYER (F.Cu) - NORMAL

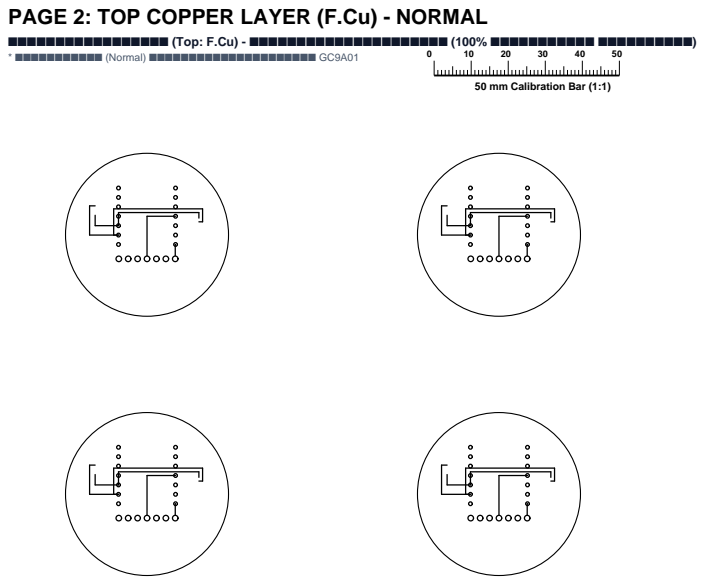
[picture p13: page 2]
■■■■■■■■■■■■■■■■■ (Top: F.Cu) - ■■■■■■■■■■■■■■■■■■■■■ (100% ■■■■■■■■■■■ ■■■■■■■■■■); * ■■■■■■■■■■■ (Normal) ■■■■■■■■■■■■■■■■■■■■■ GC9A01

50 mm Calibration Bar (1:1)

# PAGE 3: ASSEMBLY MAP & PINOUT GUIDE

■■■■■■■■■■■■■■■■■■■■■■■■■■■■■■■■■■■■■■■■■■■■■■■■■■■■■■■■■■■■■■■■■■■ (BOM)

■ ■■■■■■■■■ = ■■■■■■ (Top: GC9A01 Display)
■ ■■■■■■■■■■■■■ = ■■■■■■■■ (Bottom: MCU & Sensors)

## ■■■■■■■■■■■■■ (Bill of Materials):

- U1: Seeed Studio XIAO ESP32-C3 (MCU 2.4GHz)
- DISP1: GC9A01 240x240 Round TFT (7-Pin Header)
- U3: MPU6050 6-Axis IMU (Fall Detector 8-Pin)
- U2_CONN: Pulse Express (MAX32664D/MAX30102 JST-SH 6P)
- BZ1: Active Buzzer 9x5.5mm (3.3V)
- Q1: S8050 NPN Transistor (SOT-23)
- R1, R2: 200kΩ Resistors 1% (0805 SMD - Battery Sense)
- R3: 1kΩ Resistor (0805 SMD - Buzzer Base)
- R4: 100kΩ Resistor (0805 SMD - Pull-Down)
- C1: 100nF Capacitor (0805 SMD - ADC Filter)
- F1: 0.5A Resettable PTC Fuse (1206 SMD)
- SW1: SPDT Slide Switch (PCM12 SMD)
- J1: JST-PH 2-Pin Battery Connector (2.0mm)
- D1: SS14 Schottky Diode (SMA SMD - 5V Boost)

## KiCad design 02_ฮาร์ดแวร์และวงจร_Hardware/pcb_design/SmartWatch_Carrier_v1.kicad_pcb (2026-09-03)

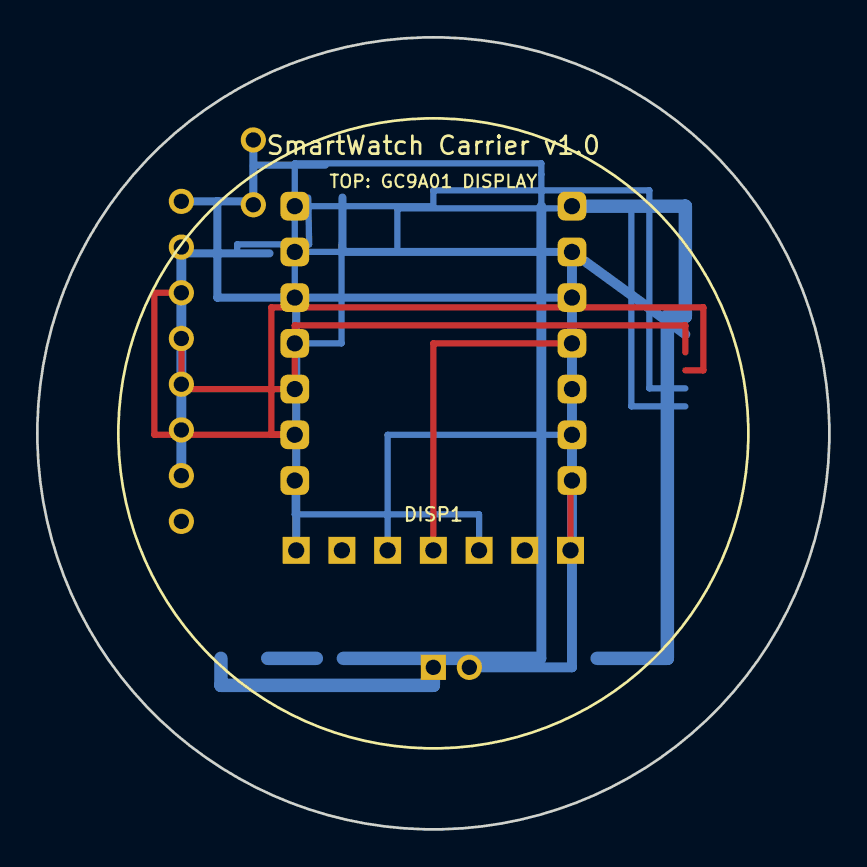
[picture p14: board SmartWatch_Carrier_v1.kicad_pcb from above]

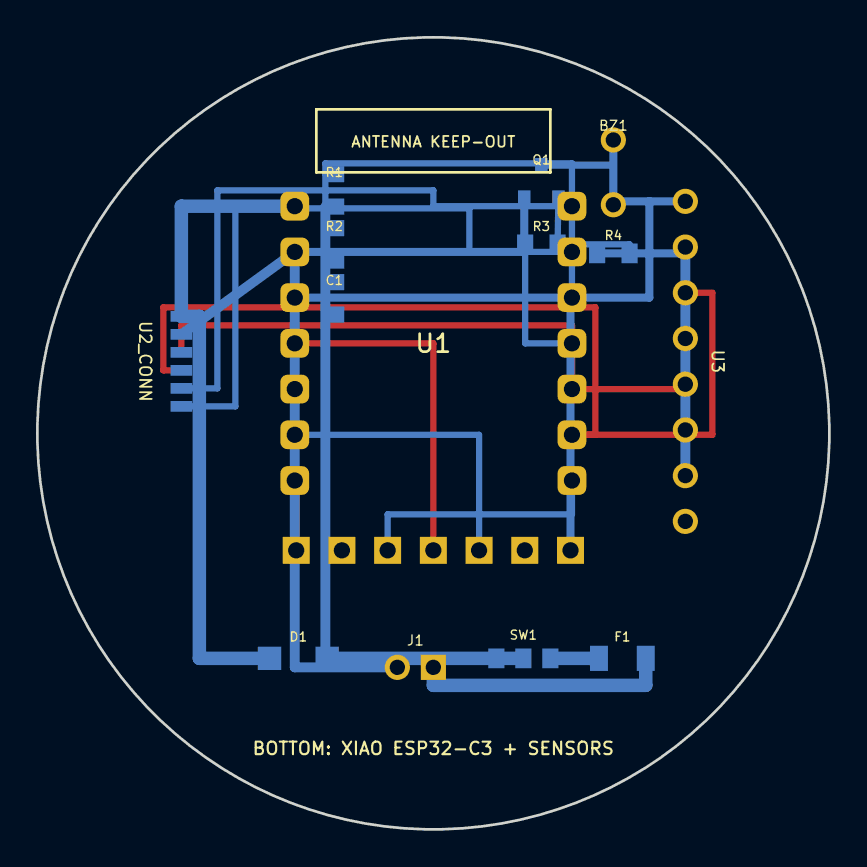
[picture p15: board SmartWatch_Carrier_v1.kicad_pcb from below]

Board: 2 copper layers, 44.0 x 44.0 mm, 15 parts (14 on the bottom side), 17 nets.

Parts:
BZ1: Buzzer_9x5.5mm
C1: C_0805_2012Metric
D1: D_SMA
DISP1: PinHeader_1x07_P2.54mm_Vertical
F1: R_1206_3216Metric
J1: JST_PH_B2B-PH-K_1x02_P2.00mm_Vertical
Q1: SOT-23
R1, R2, R3, R4: R_0805_2012Metric
SW1: SW_SPDT_PCM12
U1: Seeed_XIAO
U2_CONN: JST_SH_BM06B-SRSS-TB_1x06-1MP_P1.00mm_Vertical
U3: PinHeader_1x08_P2.54mm_Vertical

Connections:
3V3_SYS: BZ1.1, DISP1.1, U1.12, U3.1
5V_SYS: D1.2, U1.14, U2_CONN.1
ADC_BAT: C1.1, R1.2, R2.1, U1.3
BAT_SW+: R1.1, SW1.2
BUZZER_CTL: R3.1, U1.4
BUZZER_NEG: BZ1.2, Q1.3
GND_SYS: C1.2, DISP1.2, DISP1.6, J1.2, Q1.2, R2.2, R4.2, U1.13, U2_CONN.2, U3.2, U3.7
HUB_MFIO: U1.1, U2_CONN.5
HUB_RESET: U1.2, U2_CONN.6
I2C_SCL: U1.6, U2_CONN.4, U3.3
I2C_SDA: U1.5, U2_CONN.3, U3.4
Q1_BASE: Q1.1, R3.2, R4.1
SW_IN: F1.2, SW1.1
TFT_DC: DISP1.5, U1.7
TFT_MOSI: DISP1.4, U1.11
TFT_RST: DISP1.7, U1.8
TFT_SCK: DISP1.3, U1.9
